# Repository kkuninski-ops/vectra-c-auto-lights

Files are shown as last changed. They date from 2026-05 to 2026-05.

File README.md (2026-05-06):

# Vectra C Auto Lights Controller

Автоматичен контролер за управление на светлините на **Opel Vectra C 2008** с ксенон D1S.
MCU: **ESP32** с вграден Bluetooth (BLE).

## Функции

Всички функции работят **само при AUTO позиция** на копчето за светлини.
При ръчни позиции (0 / габарити / ниски) — factory поведение, контролерът не се намесва.

| Режим | Условие | Светлини |
|---|---|---|
| **Welcome** | Отключване без ключ | конфигурируемо (габарити / мъгла / ксенон) |
| **ACC** | Контакт без двигател | конфигурируемо |
| **DRL** | Двигател работи | ксенон + габарити |
| **Goodbye** | Двигател спира | конфигурируемо |

### DRL — защо така

- Ксенонът светва в момента в който алтернаторът вдига напрежението над 13.2V
- При всяко палене се вижда пълният студен старт на ксенона (синьо/лилаво → бяло) + нивелиране
- Нивелирането е независимо от нашия контролер — задейства се от сигнала на двигателя

### Конфигурация от телефон (BLE)

Свържи се с **"Vectra Auto Lights"** от BLE Terminal приложение и пиши команди:

```
set welcome.lights=GABARI+FOG
set welcome.time=30
set goodbye.lights=GABARI
set goodbye.time=60
set acc.lights=GABARI
set acc.enabled=1
status
reset
```

Вижте [docs/ble-commands.md](docs/ble-commands.md) за пълен списък.

## Хардуер накратко

- **MCU:** ESP32 DevKit v1
- **Ксенон:** IRF4905 P-MOSFET + 2N7000 драйвер (high-side, паралелно на BCM)
- **Габарити / Мъгла:** 12V реле × 2 (паралелно на BCM)
- **Входове:** 3× PC817 оптрон (ACC, AUTO, Unlock) + ADC делител (Vbat)
- **Захранване:** LM7805 от KL30 (постоянно)
- **Защити:** TVS (P6KE15A), реверсна диода, watchdog (ESP32 вграден)

## Структура на репото

```
vectra-c-auto-lights/
├── README.md
├── hardware/
│   └── schematic.md          ← ASCII схема + BOM
├── firmware/
│   ├── platformio.ini        ← PlatformIO конфигурация
│   └── src/
│       ├── main.cpp          ← setup() и loop()
│       ├── common.h          ← споделени константи
│       ├── config.h/cpp      ← конфигурация + NVS съхранение
│       ├── inputs.h/cpp      ← четене на входове + ADC
│       ├── outputs.h/cpp     ← управление на изходи
│       ├── state_machine.h/cpp ← главна логика
│       └── ble_config.h/cpp  ← Bluetooth конфигурация
├── docs/
│   ├── pinout.md             ← точки за свързване в колата
│   └── ble-commands.md       ← BLE команди
└── wiki/                     ← knowledge base
```

## Quick start

1. Инсталирай [PlatformIO](https://platformio.org/)
2. Отвори папка `firmware/` в VS Code
3. Build → Upload към ESP32
4. Свържи се по BLE и провери `status`
5. Свържи хардуера по [hardware/schematic.md](hardware/schematic.md)
6. Намери проводниците в колата по [docs/pinout.md](docs/pinout.md)

## Статус

- [x] Firmware — state machine, BLE, конфигурация
- [x] Хардуерна схема + BOM
- [ ] Намиране на AUTO и Unlock проводници в колата
- [ ] Прототип на breadboard
- [ ] Тест в кола
- [ ] Финален PCB

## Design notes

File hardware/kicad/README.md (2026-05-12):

# KiCad 10 — Vectra C Auto Lights

## Файлове

| Файл | Описание |
|---|---|
| `vectra-auto-lights.kicad_pro` | KiCad проект (design rules, net classes) |
| `vectra-auto-lights.kicad_sch` | Схема (генерирана от `generate_kicad.py`) |
| `vectra-auto-lights.kicad_pcb` | PCB layout (120×80mm, THT компоненти) |
| `generate_kicad.py` | Python скрипт — генерира `.kicad_sch` |

## Генериране на схемата

```bash
cd hardware/kicad
python3 generate_kicad.py
# → vectra-auto-lights.kicad_sch
```

## Отваряне в KiCad 10

1. Отвори `vectra-auto-lights.kicad_pro` с KiCad 10
2. **Schematic Editor** → Tools → Update Symbols from Library
3. Схемата използва **net labels** за всички връзки —
   свежи символите визуално, ако е необходимо
4. **PCB Editor** → отвори `vectra-auto-lights.kicad_pcb`
5. Tools → Update PCB from Schematic (за синхронизиране)

## PCB

- Размер: **120 × 80 mm**
- 2 слоя (F.Cu сигнали, B.Cu GND pour)
- Монтажни отвори: 4× M3 в ъглите
- Всички компоненти THT (during-hole) — лесен ръчен монтаж

## Design Rules

| Параметър | Стойност |
|---|---|
| Min track width | 0.2 mm |
| Power tracks | 0.5 mm |
| Min clearance | 0.2 mm |
| Via diameter | 0.8 mm / drill 0.4 mm |
| Power via | 1.0 mm / drill 0.6 mm |

## Конектори (JST-XH 2.54mm)

| Реф | Пинове | Функция |
|-----|---|---|
| J1 | 3 | KL30, GND, VBAT |
| J2 | 4 | KL18, AUTO, UNLOCK, GND |
| J3 | 5 | BCM_XENON, BCM_GABARI, BCM_FOG, BCM_ILLUM, GND |
| J4 | 5 | XENON_OUT, GABARI_OUT, FOG_OUT, ILLUM_OUT, GND |
| J5 | 2 | +5V → ESP32 VIN, GND |

## Gerber файлове

```bash
# В KiCad PCB Editor:
File → Fabrication Outputs → Gerbers
Output dir: gerbers/
```

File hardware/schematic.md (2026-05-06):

# Хардуерна схема — Vectra C Auto Lights

## Блок схема

```
                        ┌──────────────────────────────────────────────┐
KL30 ──[F1:1A]─────────►│ LM7805 → 5V → ESP32                         │
                        │                                              │
KL30 ──[F2:15A]────────►│ IRF4905 (P-MOSFET) → [D2] ──► Ксенон баласт│
                        │                                              │
KL30 ──[F3:5A]─────────►│ Реле K1 (Габарити)                    ESP32 │◄── BT
                        │ Реле K2 (Мъгла)                             │
                        │                                              │
Vbat ──[47k/10k]───────►│ ADC → детекция на двигател                  │
KL18 ──[PC817]─────────►│ GPIO35 — ACC вход                           │
AUTO ──[PC817]─────────►│ GPIO32 — AUTO вход                          │
UNLOCK─[PC817]─────────►│ GPIO33 — Unlock вход (interrupt)            │
                        └──────────────────────────────────────────────┘
                               │            │           │          │
                           Ксенон       Габарити      Мъгла   Illumination
                          (+BCM via D3) (+BCM via D5) (+BCM via D7) (+BCM via D10)
```

---

## Секция 1 — Захранване на контролера

```
KL30 (+12V постоянно)
  │
 [F1 — предпазител 1A]
  │
 [D1 — 1N4007] ──► (реверсна защита)
  │
 [TVS — P6KE15A] ──► GND  (защита от load dump до ~25V)
  │
 [LM7805]
  IN ──── горе
  GND ─── маса
  OUT ──► [C1: 100µF/25V] + [C2: 100nF] ──► GND
  OUT ──► ESP32 VIN (5V)
```

**Бележка:** LM7805 може да се замени с DC-DC buck (LM2596 модул) за по-малко топлина.

---

## Секция 2 — Детекция на напрежение (двигател работи)

```
KL30 (+12V)
  │
 [R1 — 47kΩ]
  │
  ├──► GPIO34 (ADC)
  │
 [R2 — 10kΩ]
  │
 GND

Vbat = Vadc × 57 / 10
Праг ON : 13.2V (алтернаторът зарежда → двигателят работи)
Праг OFF: 12.8V (хистерезис)
```

---

## Секция 3 — Входове KL18/ACC и AUTO (еднакви схеми)

```
12V сигнал (KL18 или AUTO проводник)
  │
 [R3/R5 — 4.7kΩ]
  │
 PC817 — анод
 PC817 — катод ──► GND

 PC817 — колектор ──► [R4/R6 — 10kΩ] ──► 3.3V
 PC817 — колектор ──► GPIO35 (ACC) / GPIO32 (AUTO)
 PC817 — емитер  ──► GND

Логика: 12V на входа → LED свети → транзистор ON → GPIO = LOW (активен)
```

---

## Секция 4 — Входен Unlock pulse

```
Unlock проводник (12V pulse ~200-500ms при отключване)
  │
 [R7 — 4.7kΩ]
  │
 PC817 — анод
 PC817 — катод ──► GND

 PC817 — колектор ──► [R8 — 10kΩ] ──► 3.3V
 PC817 — колектор ──► GPIO33 (FALLING interrupt)
 PC817 — емитер  ──► GND
```

---

## Секция 5 — Ксенон изход (P-MOSFET high-side)

```
KL30 [F2: 15A] ──► IRF4905 Source
                   IRF4905 Drain ──► [D2 — 1N5408] ──┐
                   IRF4905 Gate ──► [R9 — 10kΩ] ──► KL30 (pull-up → FET OFF по default)
                              └──► [Q2 — 2N7000 Drain]
                                   2N7000 Source ──► GND
                                   2N7000 Gate  ──► [R10 — 1kΩ] ──► GPIO26

BCM xenon изход ──► [D3 — 1N5408] ──┘
                                     │
                               Ксенон баласт (+12V вход)

Логика:
  GPIO26 HIGH → 2N7000 ON → IRF4905 Gate = GND → Vgs = -12V → FET ON → ксенон ON
  GPIO26 LOW  → 2N7000 OFF → R9 pulls Gate = 12V → Vgs = 0V → FET OFF
  D2/D3: развръзка — нито BCM, нито ние не се "виждат" взаимно
```

---

## Секция 6 — Реле за габарити (K1)

```
GPIO27 ──► [R11 — 1kΩ] ──► BC547 база
                            BC547 емитер ──► GND
                            BC547 колектор ──► Реле K1 бобина (-)
                            Реле K1 бобина (+) ──► KL30 [F3]
                            [D8 — 1N4007] антипаралелно на бобината (flyback)

Реле K1 NO  ──► KL30 [F3]
Реле K1 COM ──► [D4 — 1N4007] ──┐
                                  │
BCM габарити изход ──► [D5 — 1N4007] ──┘
                                        │
                                 Габарити (предни + задни)
```

---

## Секция 7 — Реле за мъгла (K2)

```
(Идентично на K1, GPIO14, D6/D7, R12)

GPIO14 ──► [R12 — 1kΩ] ──► BC547 база
                            BC547 емитер ──► GND
                            BC547 колектор ──► Реле K2 бобина (-)
                            Реле K2 бобина (+) ──► KL30 [F3]
                            [D9 — 1N4007] flyback

Реле K2 NO  ──► KL30 [F3]
Реле K2 COM ──► [D6 — 1N4007] ──┐
                                  │
BCM мъгла изход ──► [D7 — 1N4007] ──┘
                                      │
                               Предни мъгли
```

---

## Секция 8 — Illumination изход (табло + радио)

Активира illumination проводника към радиото когато нашата система е включена.
Слаботоков сигнал (~20mA) — без реле, само транзистор + диод.

```
GPIO13 ──► [R13 — 1kΩ] ──► BC547 база
                            BC547 емитер ──► GND
                            BC547 колектор ──► [D10 — 1N4007] ──┐
                                                                  │
BCM illumination изход ──► [D11 — 1N4007] ──────────────────────┘
                                                                  │
                                                    Радио illumination вход
                                                    (+ Табло illumination)

Логика:
  Нашата система активна → GPIO13 HIGH → BC547 ON → 12V към illumination → радиото дима
  MANUAL / OFF → GPIO13 LOW → BC547 OFF → BCM управлява нормално чрез D11
  D10/D11: развръзка — двата источника не се "виждат" взаимно
```

---

## ESP32 Пинове — обобщение

| GPIO | Посока | Функция |
|---|---|---|
| 34 | Вход (ADC) | Напрежение акумулатор (47k/10k делител) |
| 35 | Вход | KL18/ACC оптрон |
| 32 | Вход | AUTO сигнал оптрон |
| 33 | Вход (INT) | Unlock pulse оптрон |
| 26 | Изход | Ксенон MOSFET (2N7000 драйвер) |
| 27 | Изход | Габарити реле (BC547) |
| 14 | Изход | Мъгла реле (BC547) |
| 13 | Изход | Illumination (BC547 + диод) |

---

## BOM (Bill of Materials)

| Реф. | Компонент | Стойност | Бележка |
|---|---|---|---|
| U1 | ESP32 DevKit v1 | — | с вграден BLE |
| U2 | LM7805 | — | TO-220, с радиатор |
| Q1 | IRF4905 | P-MOSFET | TO-220, 74A, -55V |
| Q2 | 2N7000 | N-MOSFET | TO-92, IRF4905 драйвер |
| Q3, Q4, Q5 | BC547 | NPN | TO-92, реле + illumination драйвери |
| OK1 | PC817 | оптрон | KL18/ACC вход |
| OK2 | PC817 | оптрон | AUTO вход |
| OK3 | PC817 | оптрон | Unlock вход |
| K1 | Реле 12V/10A | SPDT | Габарити |
| K2 | Реле 12V/10A | SPDT | Мъгла |
| D1 | 1N4007 | диод | Реверсна защита |
| D2, D3 | 1N5408 | диод 3A | Ксенон развръзка |
| D4–D7 | 1N4007 | диод | Реле развръзка |
| D8, D9 | 1N4007 | диод | Flyback за релета |
| D10, D11 | 1N4007 | диод | Illumination развръзка |
| D12 | P6KE15A | TVS | Защита от load dump |
| R1 | 47kΩ | 1/4W | Vbat делител горе |
| R2 | 10kΩ | 1/4W | Vbat делител долу |
| R3, R5, R7 | 4.7kΩ | 1/4W | PC817 ток ограничители |
| R4, R6, R8 | 10kΩ | 1/4W | Pull-up за PC817 |
| R9 | 10kΩ | 1/4W | IRF4905 gate pull-up |
| R10 | 1kΩ | 1/4W | 2N7000 gate |
| R11, R12, R13 | 1kΩ | 1/4W | BC547 бази |
| C1 | 100µF/25V | електролит | LM7805 изход |
| C2 | 100nF | керамичен | LM7805 декуплинг |
| F1 | 1A | предпазител | MCU захранване |
| F2 | 15A | предпазител | Ксенон верига |
| F3 | 5A | предпазител | Реле захранване |

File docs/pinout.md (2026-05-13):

# Точки за свързване — Opel Vectra C (2002+)

> **Източник:** Ръководство 209, Глава 12 + Схеми на електрическата инсталация  
> ⚠️ Всеки проводник трябва да се провери с мултиметър преди свързване.  
> Цветовете на проводниците може да се различават между отделните варианти на Vectra C.

---

## Бърза справка — всички сигнали

| Сигнал | Местоположение | Проводник / Пин | Бушон | Условие |
|---|---|---|---|---|
| **+12V постоянно** | Блок в багажника, бушон F11 | Add-a-circuit адаптер | F11, 25А | Винаги |
| **Маса (GND)** | Болт за маса под капота | Черен дебел кабел | — | Винаги |
| **+12V при запалено** | ISO конектор зад радиото | Пин A7 — **червен** | F17, 15А | При запалено |
| **Подсветка табло (ILL)** | ISO конектор зад радиото | Пин A1 — **оранжев** | F17, 15А | При светлини |
| **AUTO сигнал** | Конектор на лоста за светлини (ляво от волана) | Сканирай при AUTO позиция | — | При AUTO |
| **Отключване (pulse)** | Конектор на мотора на брава — водителска врата | Проводник с +12В за ~0.3 сек | — | При отключване |
| **Габаритни светлини** | Конектор на предна фара (от моторния отсек) | Проводник с 12В само при габарити | F8, 10А | При габарити |
| **Мъгловки** | Конектор на мъгловката в предния бампер | Проводник с 12В при мъгла | F8, 10А | При мъгла |
| **Ксенон баласт** | Конектор на баласта на фарата | Жълт — 12В при къси светлини | F8, 10А | При къси светлини |

---

## Блокове с предпазители — местоположение

Колата има **три блока** с предпазители и релета:

| Блок | Местоположение | Достъп |
|---|---|---|
| **Табло (вътрешен)** | Вляво под волана, в купето | Свали капачката |
| **Под капака** | Моторен отсек, до акумулатора | Отвори капака |
| **Багажник** | В багажника, лява странична обшивка | Свали обшивката |

---

## 1. Постоянно +12V (Клема 30)

**Описание:** Захранване директно от акумулатора — има напрежение дори при изключено запалване.

| Вариант | Местоположение | Бушон |
|---|---|---|
| Акумулатор (+) | Директно, с добавен бушон 15А | Монтирай свой |
| Блок в багажника №11 | Клема 30, 25А | F11 |
| Блок в багажника №24 | Клема 30, 25А | F24 |
| Блок под капака №24 | Клема 30, 30А | F24 |

**Препоръка:** Използвай **Add-a-circuit адаптер** в блока на багажника, бушон F11 — най-лесен достъп.

---

## 2. Маса (GND)

**Описание:** Отрицателен полюс — свързан към купето на колата.

- **Под капака** — болт за маса вляво при окачването (дебел черен кабел от акумулатора)
- **В купето** — болт за маса под арматурното табло, при педалите
- **Акумулатор (-)** — директно при необходимост

---

## 3. Захранване при запалено (Клема 15 / ACC)

**Описание:** 12V само при включено запалване.

| Вариант | Местоположение | Бушон |
|---|---|---|
| Блок на таблото №17 | Комбинация от уреди, 15А | F17 |
| ISO конектор зад радиото | Пин A7 — червен проводник | — |

**Препоръка:** Вземи от **ISO конектора зад радиото**:
- Пин **A7 (червен)** = 12V при запалено
- Пин **A4 (жълт)** = 12V постоянно (Клема 30)

---

## 4. Подсветка на таблото (ILL)

**Описание:** Активира се при включени габарити или светлини — използва се за подсветка на радиото и бутоните.

| Вариант | Местоположение |
|---|---|
| ISO конектор зад радиото | Пин A1 — **оранжев** проводник |
| Конектор на превключвателя за светлини | При лоста (ляво от волана) |
| Конектор на арматурното табло | Оранжев проводник към потенциометъра за яркост |

**Препоръка:** ISO конекторът зад радиото е най-удобен — пин A1, оранжев.

---

## 5. Сигнал AUTO

**Описание:** Сигналът от AUTO позицията на превключвателя за светлини.

На Vectra C превключвателят за светлини (лост вляво от волана, компонент S121) има позиция AUTO при версиите с автоматично осветление. Ако твоята кола **няма** AUTO позиция — монтирай отделен превключвател.

**Как да намериш пина:**
1. Извади конектора на лоста за светлини
2. Завърти лоста на AUTO позиция
3. С мултиметър провери всеки пин спрямо маса
4. Пинът, на който се появява 12V **само** при AUTO = сигналът

---

## 6. Сигнал ОТКЛЮЧВАНЕ (централно заключване)

**Описание:** Кратък импулс при натискане на "отключване" на дистанционното. Идва от централния управляващ модул (BCM) към мотора на брава.

### Компоненти на централното заключване:

| Компонент | Означение | Местоположение |
|---|---|---|
| Главен управляващ модул (BCM) | A15 | Под арматурното табло |
| Модул на водителска врата | A28D | Вътре в водителска врата |
| Модул на пасажерска врата | A28P | Вътре в пасажерска врата |
| Реле централно заключване | K8 | Блок в багажника |
| Мотор на брава — водителска врата | Y13D | Водителска врата |
| Мотор на брава — пасажерска врата | Y13P | Пасажерска врата |
| Мотори на задни врати | Y35L / Y35R | Задни врати |
| Мотор на багажника | Y10 | Задна врата |

### Как да намериш сигнала:

**При мотора на брава на водителска врата (Y13D) — препоръчително:**
1. Открий конектора на мотора на брава (под обшивката на вратата)
2. Провери двата проводника с мултиметър при отключване с дистанционното
3. При **отключване**: единият проводник получава +12В за ~0.3–0.5 сек
4. При **заключване**: другият проводник получава +12В

---

## 7. Габаритни светлини

**Описание:** Лампи W 5W в предните фарове — включват се при позиция "габарити" или "светлини".

**Тип лампа:** W 5W (щифтова)  
**Местоположение:** На рефлектора на фарата, до лампата за дълги светлини  
**Достъп:** От моторния отсек, завъртане на патрона

**Как да намериш проводника:**
- Открий конектора на предната фара (от моторния отсек)
- Провери проводниците при включване **само на габарити** (без ниски светлини)
- Проводникът, на който се появява 12В = сигналът

**Бушон:** Блок под капака, №8 — Фарове, 10А

---

## 8. Мъгловки (противотуманни фарове)

**Описание:** H3 55W лампи в предния бампер.

**Тип лампа:** H3, 55W  
**Местоположение:** В предния бампер, долна позиция  
**Достъп:** Отдолу или след сваляне на обшивката на бампера

**Как да намериш проводника:**
- Открий конектора на мъгловката (вдясно или вляво в бампера)
- Провери при включване **само на мъгловките**
- Проводникът с 12В = сигналът

---

## 9. Ксенонов баласт

**Описание:** Ксенонови фарове D2S — баластът получава 12V при включени къси светлини.

**Тип лампа:** D2S  
**Местоположение:** Баластът е монтиран директно на фарата  
**Бушон:** Блок под капака, №8 — Фарове, 10А

| Проводник | Описание | Типичен цвят |
|---|---|---|
| Захранване | +12V при включени къси светлини | Жълт |
| Маса | GND | Кафяв / черен |

> ⚠️ **Внимание:** Не докосвай проводниците **към самата лампа** — около 25 000V при стартиране!  
> Свързвай се само към проводниците от управляващия модул **към баласта**.

---

## Ред при монтаж

1. **Изключи акумулатора** преди работа
2. **KL30** — Add-a-circuit в блока на багажника, бушон F11
3. **Маса** — болт под капота
4. **KL15 и ILL** — ISO конектор зад радиото (пин A7 и A1)
5. **ОТКЛЮЧВАНЕ** — конектор на мотора на брава на водителска врата
6. **Габарити** — конектор на предна фара
7. **Мъгловки** — конектор на мъгловката в бампера
8. **Ксенон** — конектор на баласта
9. **AUTO** — конектор на лоста за светлини

---

## Инструменти

| Инструмент | Употреба |
|---|---|
| Мултиметър (20V DC) | Намиране на сигнали |
| Игловидна сонда | Пробиване на изолацията без рязане |
| Posi-Tap конектори | Захващане без рязане на проводника |
| Add-a-circuit адаптер | За бушоните |
| 12V тест лампа | Бързо проверяване на импулси |

---

> 📖 **Схеми в ръководството:** Схема 9–11 (централно заключване, стр. 328–330) · Схема 13 (осветление и табло, стр. 332) · Схема 16 (фарове и мъгловки, стр. 335)

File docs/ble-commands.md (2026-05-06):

# Bluetooth конфигурация

## Свързване

1. Инсталирай **"Serial Bluetooth Terminal"** (Android) или **"BLE Terminal HM-10"** (iOS)
2. Включи контакта на колата (ESP32 се захранва от KL30 — включен е винаги)
3. В приложението: търси устройство **"Vectra Auto Lights"**
4. Свържи се → избери **Nordic UART Service**
5. Пиши команди в конзолата

---

## Команди

### `status`
Показва текущото състояние и всички настройки.

```
Състояние: DRL
Акумулатор: 14.12V

welcome.lights  = GABARI+FOG
welcome.time    = 30s
goodbye.lights  = GABARI
goodbye.time    = 45s
acc.lights      = GABARI
acc.enabled     = yes
```

### `set KEY=VALUE`
Сменя настройка. Записва се автоматично в паметта.

**Примери:**
```
set welcome.lights=GABARI+FOG+XENON
set welcome.time=20
set goodbye.lights=GABARI
set goodbye.time=60
set acc.lights=GABARI
set acc.enabled=0
set acc.enabled=1
```

**Стойности за светлини:**
- `GABARI` — само габарити (предни + задни)
- `FOG` — само предни мъгли
- `XENON` — само ксенон (⚠️ студен старт!)
- `GABARI+FOG` — комбинация
- `GABARI+FOG+XENON` — всичко
- `NONE` — нищо (изключен режим)

### `reset`
Връща всички настройки към стойностите по подразбиране.

### `help`
Показва кратка помощ.

---

## Настройки по подразбиране

| Настройка | Default |
|---|---|
| welcome.lights | GABARI |
| welcome.time | 30s |
| goodbye.lights | GABARI |
| goodbye.time | 30s |
| acc.lights | GABARI |
| acc.enabled | yes |

---

## Бележка за ксенон в welcome/goodbye

D1S ксенонът има ограничен брой студени старта. Ако е включен в welcome lights, след края на таймера ще се изгаси, и след малко ще се запали отново при стартиране на двигателя — **два студени старта наведнъж**.

Изключение: ако двигателят запали по време на welcome таймера, ксенонът **не се изгася** — директно преминава в DRL режим.

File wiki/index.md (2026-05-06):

# Wiki Index — Vectra C Auto Lights

## Entities

*(добавяй при ingest на нови sources)*

| Файл | Описание |
|---|---|
| — | — |

## Concepts

| Файл | Описание |
|---|---|
| — | — |

## Sources

| Файл | Тип | Описание |
|---|-----|---|
| — | — | — |

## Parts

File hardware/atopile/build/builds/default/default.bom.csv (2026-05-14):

Designator | Footprint | Quantity | Value | Manufacturer | Partnumber | LCSC Part #
C1 | Nichicon_UBT1E101MPD1TD:CAP-TH_BD8.0-P3.50-D0.5-FD | 1 |  | Nichicon | UBT1E101MPD1TD | C1579560
C2 | KEMET_C315C104M5U5TA:C_Disc_D5.0mm_W2.5mm_P2.50mm | 1 |  | KEMET | C315C104M5U5TA | C1711
D1, D2, D3, D4, D5, D6, D7, D8, D9 | ST_1N4007:DO-41_BD2.4-L4.7-P8.70-D0.9-RD | 9 |  | ST | 1N4007 | C106903
D10 | RUILON_P6KE15A:DO-15_BD3.1-L6.7-P10.70-D0.9-FD | 1 |  | RUILON | P6KE15A | C10182
D11, D12 | MDD_Microdiode_Electronics_1N5408:DO-201_BD5.3-L9.5-P13.50-D1.4-RD | 2 |  | MDD（Microdiode Electronics） | 1N5408 | C2460
F1, F2, F3 | Schurter_FuseHolder_5x20:Fuseholder_Cylinder-5x20mm_Schurter_0031_8201_Horizontal_Open | 3 |  | Schurter | 0031.8201 | C2837835
J1 | BOOMELE_PinHeader_1x2_P254:PinHeader_1x02_P2.54mm_Vertical | 1 |  | BOOMELE | 2.54-1*2P | C49256
J2 | BOOMELE_PinHeader_1x4_P254:PinHeader_1x04_P2.54mm_Vertical | 1 |  | BOOMELE | 2.54-1*4P | C49661
J3, J4, J5, J6 | BOOMELE_2_54_1_3P:HDR-TH_3P-P2.54-V-M-1 | 4 |  | BOOMELE | 2.54-1*3P针 | C49257
K1, K2 | Ningbo_Songle_Relay_SRD_12VDC_SL_C:RELAY-TH_SRD-XXVDC-XL-C | 2 |  | Ningbo Songle Relay | SRD-12VDC-SL-C | C30431
Q1, Q2, Q3 | Jiangsu_Changjing_Electronics_Technology_Co___Ltd_BC547:TO-92-3_L4.9-W3.7-P1.27-L | 3 |  | Jiangsu Changjing Electronics Technology Co., Ltd. | BC547 | C47089404
Q4 | Vishay_IRF4905PBF:TO-220-3_Vertical | 1 |  | Vishay | IRF4905PBF | C2564
Q5 | Changjiang_Electronics_Tech_2N7000:TO-92-3_L4.9-W3.7-P1.27-L | 1 |  | Changjiang Electronics Tech | 2N7000 | C9114
R1, R2, R3, R13 | UNI_ROYAL_MFR0W4F1000A50:RES-TH_BD2.2-L6.5-P10.50-D0.6 | 4 |  | UNI-ROYAL | MFR0W4F1000A50 | C57438
R4, R6, R8 | UNI_ROYAL_MFR0W4F4701A50:RES-TH_BD2.2-L6.5-P10.50-D0.6 | 3 |  | UNI-ROYAL | MFR0W4F4701A50 | C57204
R5, R7, R9, R11, R12 | UNI_ROYAL_MFR0W4F1002A50:RES-TH_BD2.5-L6.5-P10.50-D0.6 | 5 |  | UNI-ROYAL | MFR0W4F1002A50 | C57436
R10 | UNI_ROYAL_MFR0W4F4702A50:RES-TH_BD2.5-L6.5-P10.50-D0.6 | 1 |  | UNI-ROYAL | MFR0W4F4702A50 | C58605
U1, U2, U3 | UMW_PC817C:DIP-4_L4.6-W6.5-P2.54-LS7.6-BL | 3 |  | UMW | PC817C | C3008368
U4 | HGSEMI_LM7805CT:TO-220-3_L10.0-W4.5-P2.54-L | 1 |  | HGSEMI | LM7805CT | C725349
U5 | Espressif_Systems_ESP32_WROOM_32E_N4:WIFI-SMD_ESP32-WROOM-32E | 1 |  | Espressif Systems | ESP32-WROOM-32E-N4 | C701341

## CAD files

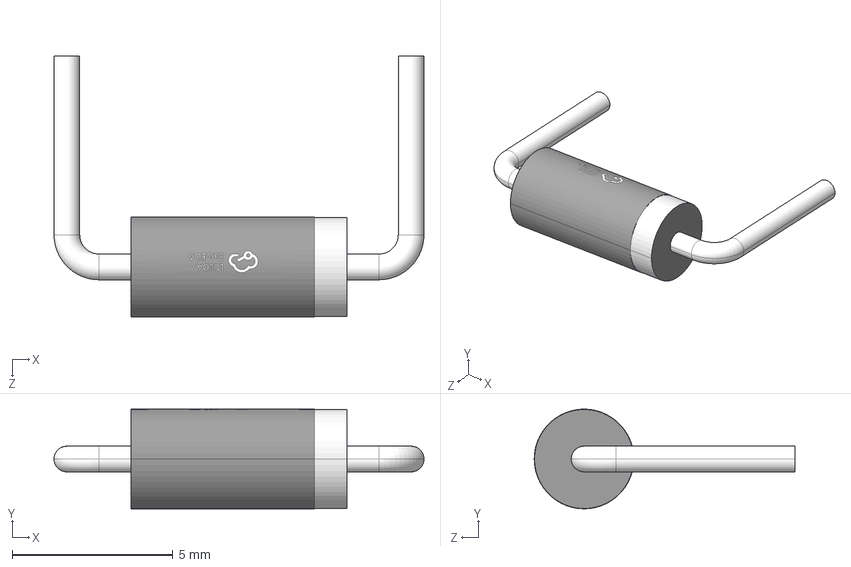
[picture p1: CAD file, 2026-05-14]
hardware/atopile/build/cache/parts/easyeda/C10182/DO-15_BD3.1-L6.7-P10.70-D0.9-FD.step
11.5 x 3.10 x 8.10 mm

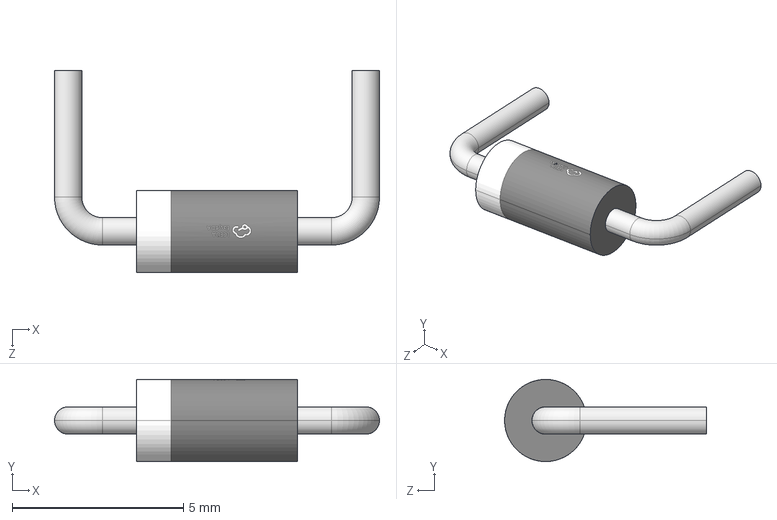
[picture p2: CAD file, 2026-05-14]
hardware/atopile/build/cache/parts/easyeda/C106903/DO-41_D2.4-L4.7-P8.70.step
9.50 x 2.40 x 5.90 mm

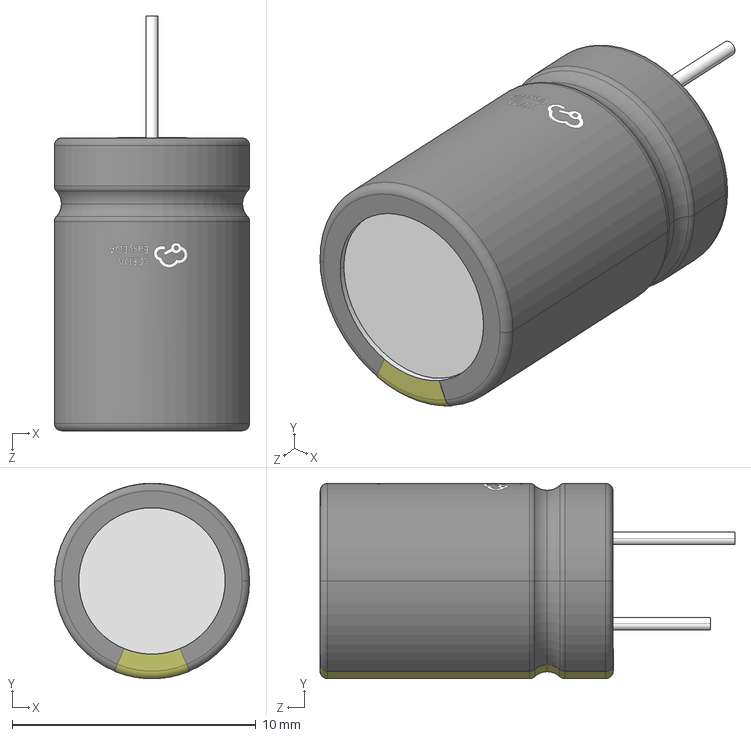
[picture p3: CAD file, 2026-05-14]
hardware/atopile/build/cache/parts/easyeda/C1579560/CAP-TH_BD8.0-P3.50-D0.5-FD.step
8.00 x 8.00 x 17.0 mm

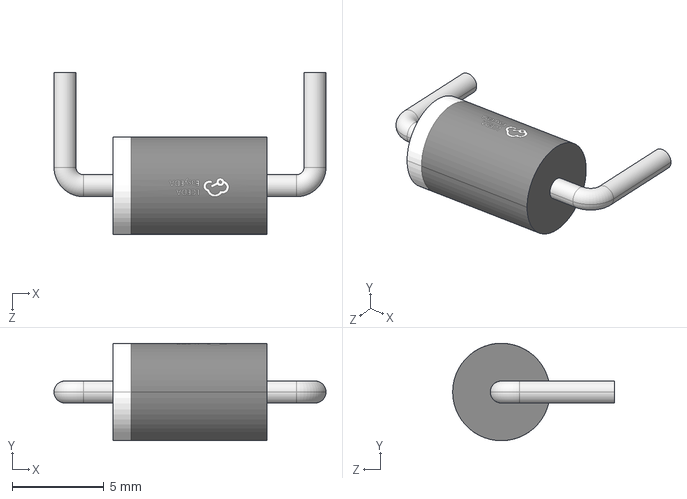
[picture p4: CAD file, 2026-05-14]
hardware/atopile/build/cache/parts/easyeda/C2460/DO-201AD_D5.3-L8.4-P13.6.step
14.8 x 5.30 x 8.80 mm

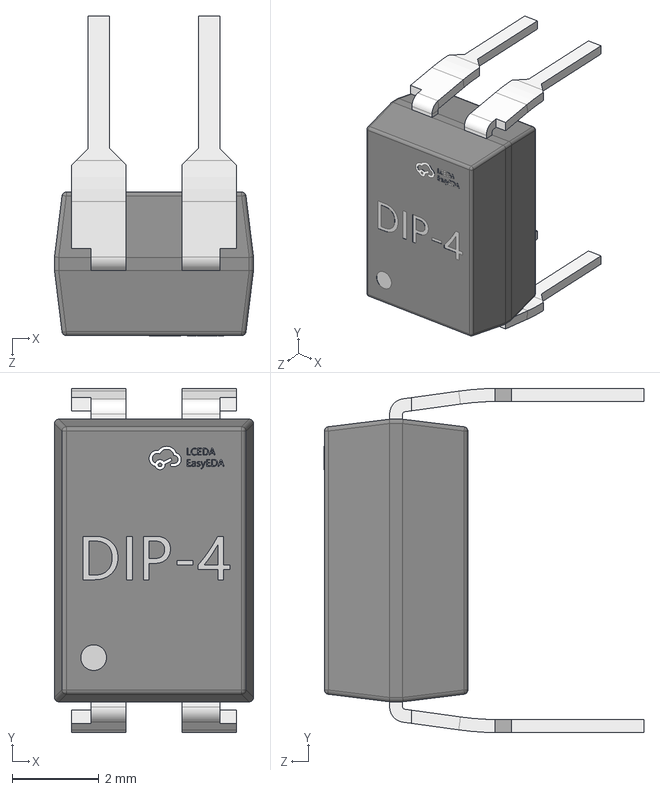
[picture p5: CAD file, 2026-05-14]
hardware/atopile/build/cache/parts/easyeda/C3008368/DIP-4_L4.6-W6.5-H3.5-LS7.62-P2.54.step
4.58 x 7.92 x 7.36 mm

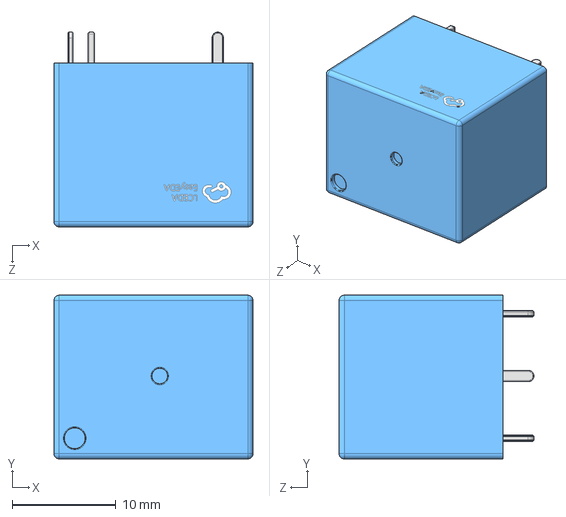
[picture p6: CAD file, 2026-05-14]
hardware/atopile/build/cache/parts/easyeda/C30431/RELAY-TH_L19.2-W15.6-H15.8.step
19.2 x 15.8 x 18.8 mm

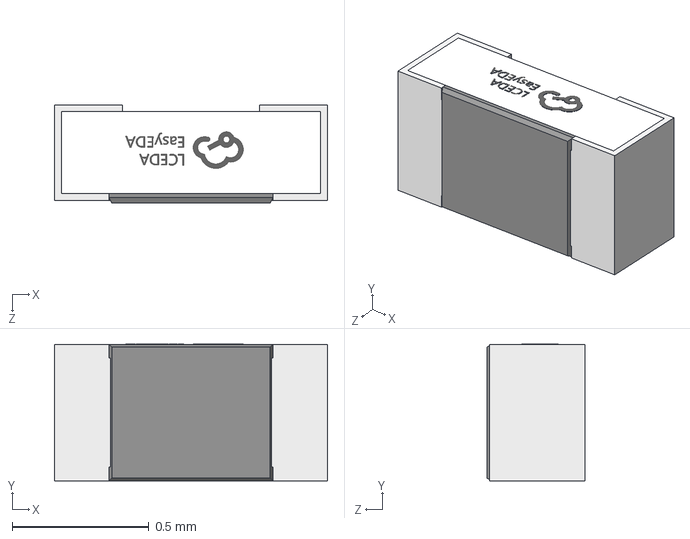
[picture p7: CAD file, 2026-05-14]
hardware/atopile/build/cache/parts/easyeda/C36871/R0402_L1.0-W0.5-H0.4.step
1.00 x 0.501 x 0.36 mm

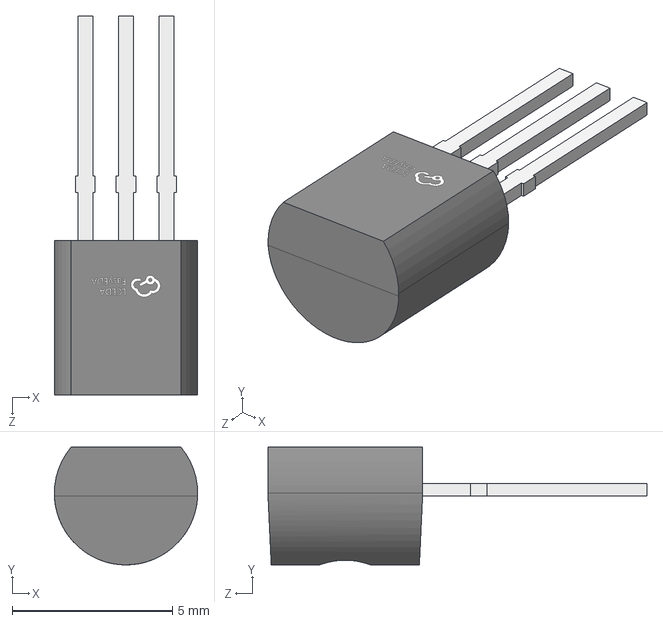
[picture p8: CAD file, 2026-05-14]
hardware/atopile/build/cache/parts/easyeda/C47089404/TO-92-3_L4.9-W3.7-P1.27-L.step
4.48 x 3.68 x 11.8 mm

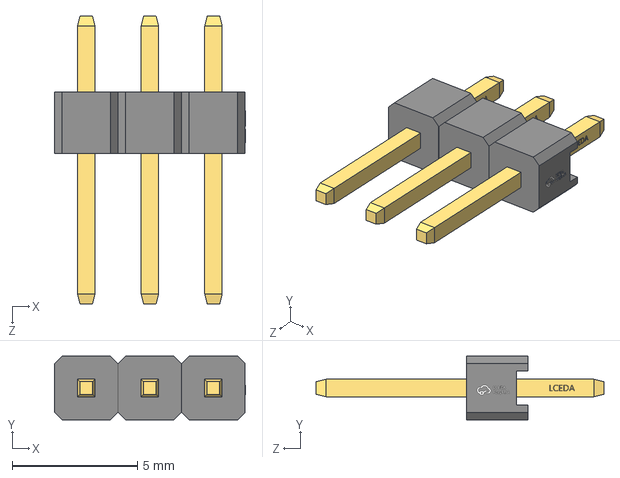
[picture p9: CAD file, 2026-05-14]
hardware/atopile/build/cache/parts/easyeda/C49257/HDR-M-2.54_1x3.step
7.63 x 2.54 x 11.5 mm

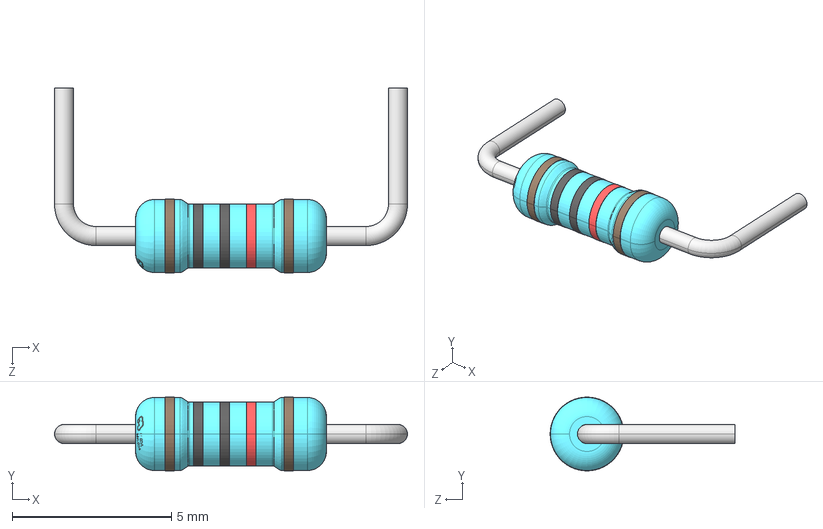
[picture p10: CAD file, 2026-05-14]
hardware/atopile/build/cache/parts/easyeda/C57204/RES-TH_BD2.2-L6.5-P10.50-D0.6.step
11.1 x 2.32 x 5.81 mm

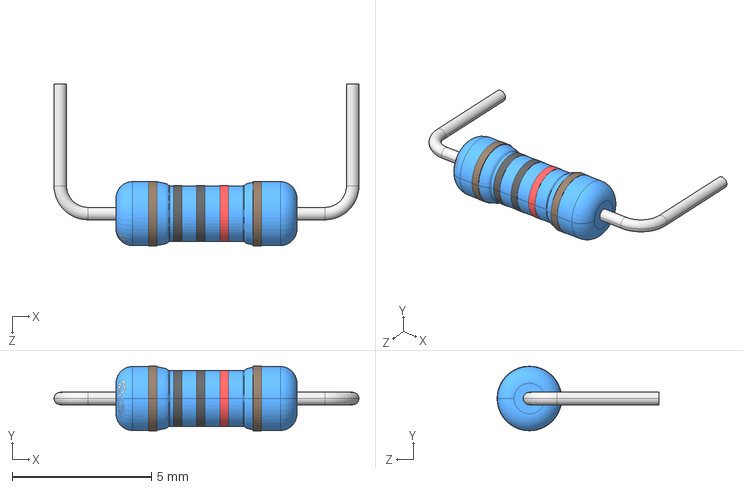
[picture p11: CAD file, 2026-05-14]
hardware/atopile/build/cache/parts/easyeda/C57436/RES-TH_D2.3-L6.5-P10.50.step
11.0 x 2.32 x 5.81 mm

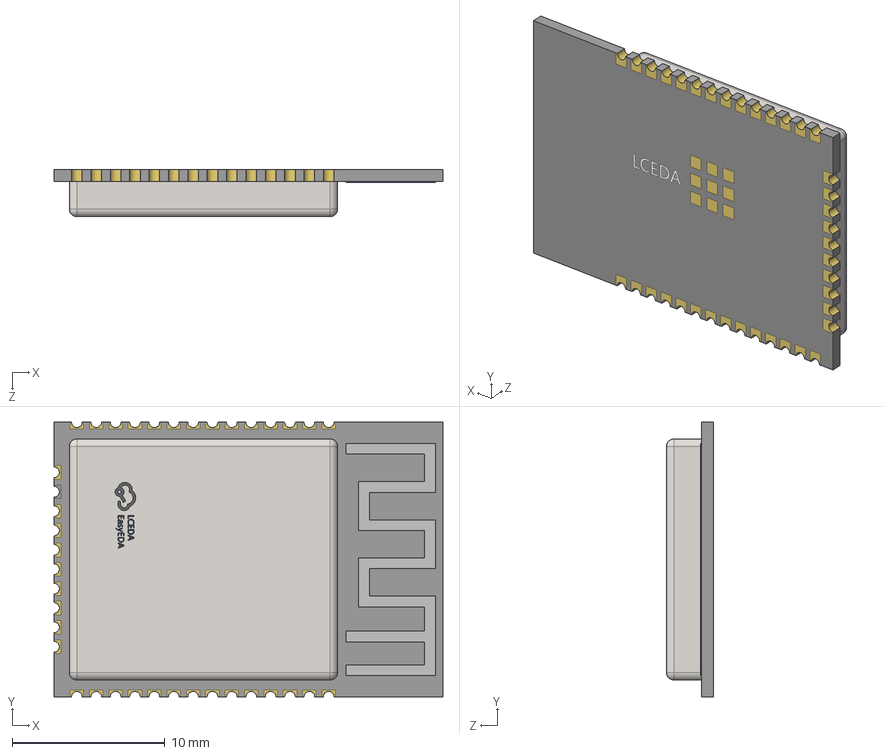
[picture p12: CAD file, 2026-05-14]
hardware/atopile/build/cache/parts/easyeda/C701341/WIFI-SMD_L25.5-W18.0-H3.1-ESP32-WROOM-32E.step
25.5 x 18.0 x 3.10 mm

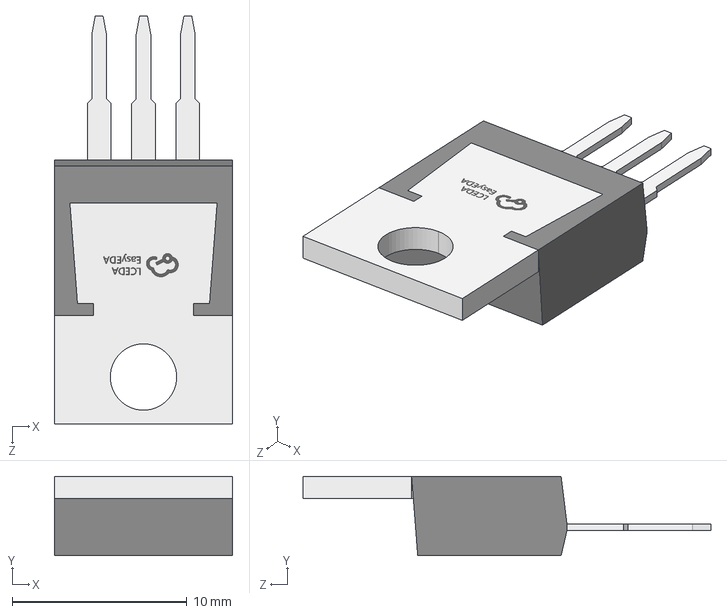
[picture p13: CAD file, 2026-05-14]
hardware/atopile/build/cache/parts/easyeda/C725349/TO-220-3_L10.0-W4.5-P2.54-L.step
10.2 x 4.54 x 23.4 mm

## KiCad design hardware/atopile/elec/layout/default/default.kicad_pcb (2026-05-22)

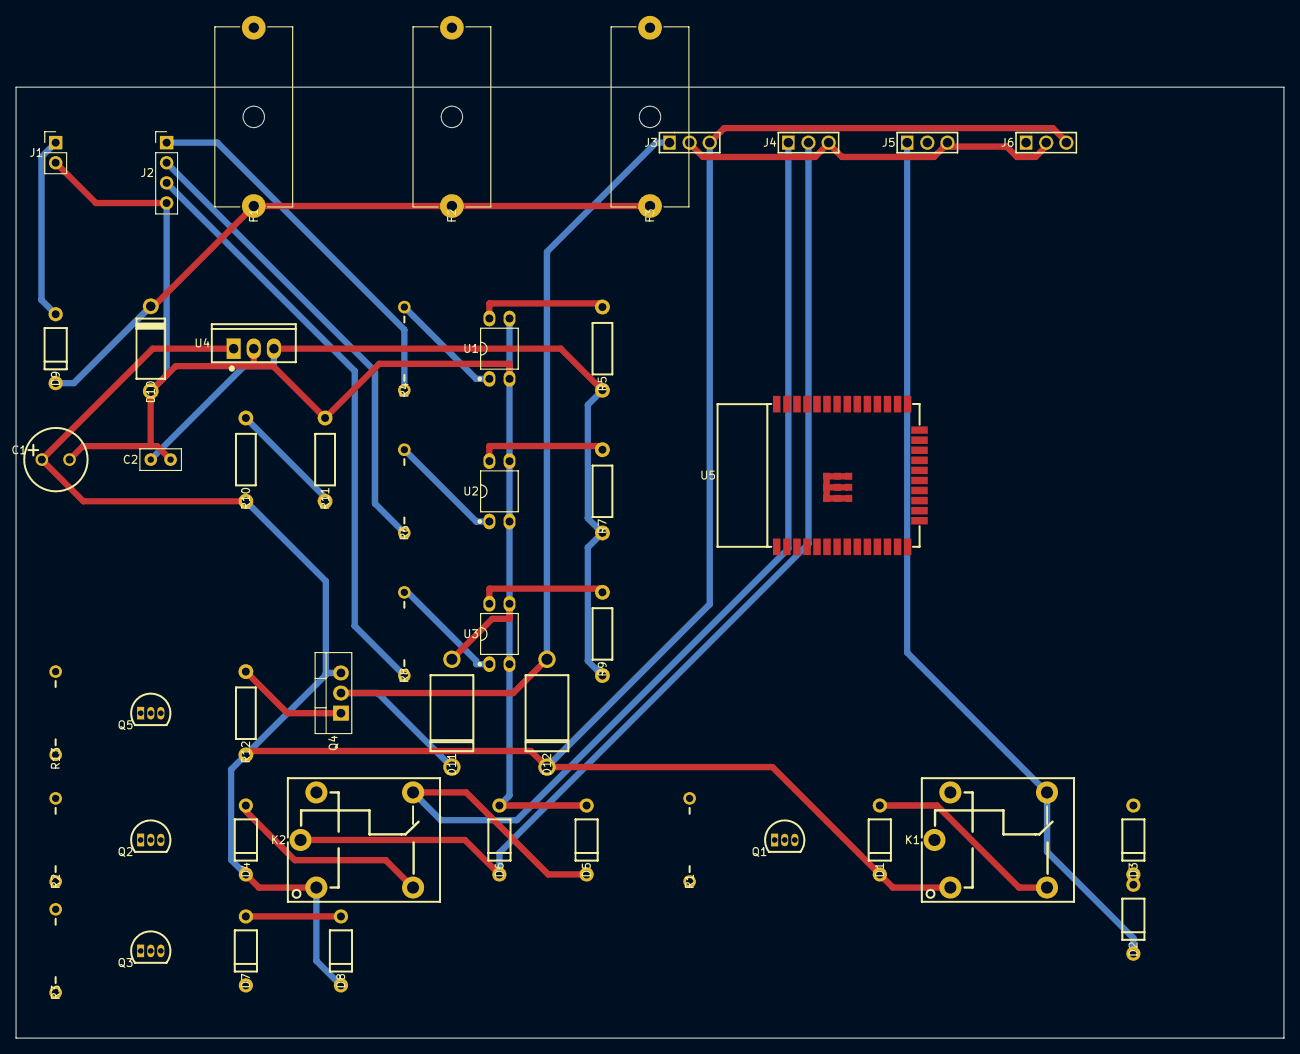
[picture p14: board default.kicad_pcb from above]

Board: 2 copper layers, 160.0 x 120.0 mm, 48 parts (0 on the bottom side), 32 nets.

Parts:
C1: CAP-TH_BD8.0-P3.50-D0.5-FD
C2: C_Disc_D5.0mm_W2.5mm_P2.50mm
D1, D2, D3, D4, D5, D6, D7, D8, D9: DO-41_BD2.4-L4.7-P8.70-D0.9-RD
D10: DO-15_BD3.1-L6.7-P10.70-D0.9-FD
D11, D12: DO-201_BD5.3-L9.5-P13.50-D1.4-RD
F1, F2, F3: Fuseholder_Cylinder-5x20mm_Schurter_0031_8201_Horizontal_Op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
J1: PinHeader_1x02_P2.54mm_Vertical
J2: PinHeader_1x04_P2.54mm_Vertical
J3, J4, J5, J6: HDR-TH_3P-P2.54-V-M-1
K1, K2: RELAY-TH_SRD-XXVDC-XL-C
Q1, Q2, Q3, Q5: TO-92-3_L4.9-W3.7-P1.27-L
Q4: TO-220-3_Vertical
R1, R2, R3, R4, R6, R8, R13: RES-TH_BD2.2-L6.5-P10.50-D0.6
R5, R7, R9, R10, R11, R12: RES-TH_BD2.5-L6.5-P10.50-D0.6
U1, U2, U3: DIP-4_L4.6-W6.5-P2.54-LS7.6-BL
U4: TO-220-3_L10.0-W4.5-P2.54-L
U5: WIFI-SMD_ESP32-WROOM-32E

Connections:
1: D9.1, D10.2, F1.1, F2.1, F3.1
2: D1.2, K1.2, Q1.1
AN: R4.2, U1.1
D: Q4.1, Q5.3, R12.2
com: D2.1, J5.1, K1.3
com-1: D5.1, J4.1, K2.3
ctrl: R1.1, U5.33
ctrl-1: R2.1, U5.31
ctrl-2: R3.1, U5.36
ctrl-3: R13.1, U5.30
fog-2: Q1.2, R1.2
gabari-2: D4.2, K2.2, Q2.1
gabari-2-1: Q2.2, R2.2
gnd: C1.2, C2.2, D2.2, D3.2, D5.2, D6.2, D7.2, D8.2, D10.1, D11.2, J1.2, J2.4, J3.2, J4.3, J5.3, J6.2, Q1.3, Q2.3, Q3.3, Q5.1, R11.2, U1.2, U1.3, U2.2, U2.3, U3.2, U3.3, U4.2, U5.1, U5.15, U5.38, U5.39
illum-2: Q3.2, R3.2
no: D3.1, J5.2, K1.5
no-1: D6.1, J4.2, K2.5
ok2-AN: R6.2, U2.1
ok3-AN: R8.2, U3.1
out_illum: D7.1, J6.1, Q3.1
out_xenon: D11.1, D12.2, J3.1, Q4.2
sig_auto: J2.2, R6.1
sig_in: J2.1, R4.1
sig_out: R5.2, U1.4, U5.27
sig_out-1: R7.2, U2.4, U5.28
sig_out-2: R9.2, U3.4, U5.29
sig_unlock: J2.3, R8.1
v12: C1.1, D1.1, D4.1, D8.1, D12.1, F1.2, F2.2, F3.2, J3.3, J6.3, K1.1, K2.1, Q4.3, R10.1, R12.1, U4.1
v33: C2.1, R5.1, R7.1, R9.1, U4.3, U5.2
vin_raw: D9.2, J1.1
vout: R10.2, R11.1, U5.26
xenon-2: Q5.2, R13.2

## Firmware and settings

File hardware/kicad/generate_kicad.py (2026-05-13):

#!/usr/bin/env python3
"""
Vectra C Auto Lights — KiCad 10 Schematic Generator
Generates: vectra-auto-lights.kicad_sch

Usage:
    cd hardware/kicad
    python3 generate_kicad.py
    # → отвори vectra-auto-lights.kicad_sch в KiCad 10

Схемата използва net labels за всички връзки.
След отваряне в KiCad: свържи всеки пин с nearby label (5-10 мин работа).
"""

import uuid
import os

OUT = os.path.join(os.path.dirname(__file__), "vectra-auto-lights.kicad_sch")

# ── Helpers ───────────────────────────────────────────────────────────

def uid():
    return str(uuid.uuid4())

def prop(name, val, x=0, y=0, rot=0, hide=False):
    h = " hide" if hide else ""
    return (f'    (property "{name}" "{val}" (at {x:.4f} {y:.4f} {rot})\n'
            f'      (effects (font (size 1.27 1.27)){h})\n'
            f'    )')

def label(net, x, y, rot=0):
    return (f'  (label "{net}" (at {x:.4f} {y:.4f} {rot})\n'
            f'    (effects (font (size 1.27 1.27)) (justify left))\n'
            f'    (uuid "{uid()}")\n'
            f'  )')

def wire(x1, y1, x2, y2):
    return (f'  (wire (pts (xy {x1:.4f} {y1:.4f}) (xy {x2:.4f} {y2:.4f}))\n'
            f'    (stroke (width 0) (type default))\n'
            f'    (uuid "{uid()}")\n'
            f'  )')

def no_connect(x, y):
    return f'  (no_connect (at {x:.4f} {y:.4f}) (uuid "{uid()}"))'

def power_symbol(name, x, y):
    """Power rail symbol (+12V, +5V, GND)"""
    return (f'  (symbol (lib_id "power:{name}") (at {x:.4f} {y:.4f} 0) (unit 1)\n'
            f'    (exclude_from_sim no) (in_bom yes) (on_board yes)\n'
            f'    (uuid "{uid()}")\n'
            f'{prop("Reference", f"#{name}", x, y-2.54, 0, True)}\n'
            f'{prop("Value", name, x, y+2.54, 0)}\n'
            f'    (pin "1" (uuid "{uid()}"))\n'
            f'  )')

# ── Component factory ─────────────────────────────────────────────────

class Comp:
    """Builds a KiCad symbol instance."""
    def __init__(self, lib_id, ref, value, x, y, rot=0, footprint="", datasheet="~"):
        self.lib_id    = lib_id
        self.ref       = ref
        self.value     = value
        self.x         = x
        self.y         = y
        self.rot       = rot
        self.footprint = footprint
        self.datasheet = datasheet
        self.pins      = {}   # name → (dx, dy)  offsets relative to component center
        self.labels    = []   # (net, dx, dy) for auto-labels

    def pin_label(self, net, dx, dy):
        """Add a net label near a pin."""
        self.labels.append((net, dx, dy))
        return self

    def render(self):
        lines = [
            f'  (symbol (lib_id "{self.lib_id}") (at {self.x:.4f} {self.y:.4f} {self.rot}) (unit 1)',
            f'    (exclude_from_sim no) (in_bom yes) (on_board yes)',
            f'    (uuid "{uid()}")',
            prop("Reference", self.ref,    self.x+1,   self.y-2.54, 0),
            prop("Value",     self.value,  self.x+1,   self.y+2.54, 0),
            prop("Footprint", self.footprint, self.x, self.y, 0, True),
            prop("Datasheet", self.datasheet, self.x, self.y, 0, True),
        ]
        # Generic pin UUIDs (1..8)
        for i in range(1, 9):
            lines.append(f'    (pin "{i}" (uuid "{uid()}"))')
        lines.append('  )')
        # Net labels near pins
        for (net, dx, dy) in self.labels:
            lines.append(label(net, self.x + dx, self.y + dy))
        return "\n".join(lines)


# ── Net definitions ───────────────────────────────────────────────────
# Naming convention:
#   PWR_12V, PWR_5V, GND      — power rails
#   KL18_RAW, AUTO_RAW        — 12V raw car signals (before optocouplers)
#   UNLOCK_RAW                — 12V unlock pulse
#   ACC_GPIO, AUTO_GPIO       — 3.3V signals to ESP32 (after optocouplers)
#   UNLOCK_GPIO               — 3.3V unlock to ESP32
#   VBAT_ADC                  — voltage divider output to ESP32 ADC
#   GPIO13..GPIO35            — ESP32 GPIO outputs/inputs
#   XENON_GATE                — 2N7000 drain / IRF4905 gate
#   XENON_SW                  — IRF4905 drain (our xenon output, before diode)
#   BCM_XENON                 — BCM xenon output (before diode)
#   XENON_BALLAST             — final +12V to xenon ballast
#   GABARI_SW                 — relay K1 NO contact
#   BCM_GABARI                — BCM gabari output
#   GABARI_WIRE               — final gabari output to car
#   FOG_SW                    — relay K2 NO contact
#   BCM_FOG                   — BCM fog output
#   FOG_WIRE                  — final fog output to car
#   ILLUM_SW                  — our illumination transistor output
#   BCM_ILLUM                 — BCM illumination output
#   ILLUM_WIRE                — final illumination to radio
#   XENON_PWR                 — +12V fused 15A (xenon power)
#   RELAY_PWR                 — +12V fused 5A (relay power)
#   RELAY_K1_COIL_N           — K1 coil negative (collector Q3)
#   RELAY_K2_COIL_N           — K2 coil negative (collector Q4)


# ── Build component list ──────────────────────────────────────────────

components = []

# ═══════════════════════════════════════════════════════════════════════
# БЛОК A — ЗАХРАНВАНЕ  (x: 15-110, y: 15-55)
# ═══════════════════════════════════════════════════════════════════════

# J1 — КL30 + GND вход (2-pin)
j1 = Comp("Connector:Conn_01x02_Pin", "J1", "KL30+GND", 18, 28,
           footprint="Connector_PinHeader_2.54mm:PinHeader_1x02_P2.54mm_Vertical")
j1.pin_label("PWR_12V",  5,  -2.54)
j1.pin_label("GND",      5,   2.54)
components.append(j1)

# F1 — предпазител 1A (MCU)
f1 = Comp("Device:Fuse", "F1", "1A", 38, 20,
          footprint="Fuse:Fuseholder_Littelfuse_64900001039_1x1_P5.08mm_Vertical")
f1.pin_label("PWR_12V",  -5,  0)
f1.pin_label("PWR_12V_1A", 5,  0)
components.append(f1)

# F2 — предпазител 15A (ксенон)
f2 = Comp("Device:Fuse", "F2", "15A", 38, 30,
          footprint="Fuse:Fuseholder_Littelfuse_64900001039_1x1_P5.08mm_Vertical")
f2.pin_label("PWR_12V",    -5, 0)
f2.pin_label("XENON_PWR",   5, 0)
components.append(f2)

# F3 — предпазител 5A (релета)
f3 = Comp("Device:Fuse", "F3", "5A", 38, 40,
          footprint="Fuse:Fuseholder_Littelfuse_64900001039_1x1_P5.08mm_Vertical")
f3.pin_label("PWR_12V",  -5, 0)
f3.pin_label("RELAY_PWR", 5, 0)
components.append(f3)

# D1 — 1N4007 реверсна защита
d1 = Comp("Device:D", "D1", "1N4007", 62, 20,
          footprint="Diode_THT:D_DO-41_SOD81_P10.16mm_Horizontal")
d1.pin_label("PWR_12V_1A", -5, 0)
d1.pin_label("PWR_12V_PROT", 5, 0)
components.append(d1)

# D12 — TVS P6KE15A
d12 = Comp("Device:TVS", "D12", "P6KE15A", 62, 32,
           footprint="Diode_THT:D_DO-41_SOD81_P10.16mm_Horizontal")
d12.pin_label("PWR_12V_PROT", -5, 0)
d12.pin_label("GND",           5, 0)
components.append(d12)

# U2 — LM7805
u2 = Comp("Regulator_Linear:LM7805", "U2", "LM7805", 85, 25,
          footprint="Package_TO_SOT_THT:TO-220-3_Vertical")
u2.pin_label("PWR_12V_PROT", -7.62, 0)
u2.pin_label("GND",           0,    7.62)
u2.pin_label("PWR_5V",        7.62, 0)
components.append(u2)

# C1 — 100µF
c1 = Comp("Device:C", "C1", "100uF/25V", 105, 20,
          footprint="Capacitor_THT:C_Radial_D8.0mm_H11.5mm_P3.50mm")
c1.pin_label("PWR_5V", 0, -5)
c1.pin_label("GND",    0,  5)
components.append(c1)

# C2 — 100nF
c2 = Comp("Device:C", "C2", "100nF", 113, 20,
          footprint="Capacitor_THT:C_Disc_D3.8mm_W2.6mm_P2.50mm")
c2.pin_label("PWR_5V", 0, -5)
c2.pin_label("GND",    0,  5)
components.append(c2)

# ═══════════════════════════════════════════════════════════════════════
# БЛОК B — VOLTAGE DIVIDER  (x: 15-55, y: 65-105)
# ═══════════════════════════════════════════════════════════════════════

# R1 — 47kΩ (горе)
r1 = Comp("Device:R", "R1", "47k", 30, 72, rot=0,
          footprint="Resistor_THT:R_Axial_DIN0207_L6.3mm_D2.5mm_P10.16mm_Horizontal")
r1.pin_label("XENON_PWR",  0, -5)   # top → 12V (sense от F2 или акумулатор)
r1.pin_label("VBAT_ADC",   0,  5)   # bottom → to R2 junction
components.append(r1)

# R2 — 10kΩ (долу)
r2 = Comp("Device:R", "R2", "10k", 30, 87, rot=0,
          footprint="Resistor_THT:R_Axial_DIN0207_L6.3mm_D2.5mm_P10.16mm_Horizontal")
r2.pin_label("VBAT_ADC", 0, -5)   # top → to R1 junction
r2.pin_label("GND",       0,  5)  # bottom → GND
components.append(r2)

# ═══════════════════════════════════════════════════════════════════════
# БЛОК C — ОПТРОНИ  (x: 25-95, y: 110-185)
# ═══════════════════════════════════════════════════════════════════════

opto_data = [
    # (ref, y, net_anode_resistor, net_input, net_output, gpio_net)
    ("OK1", 118, "KL18_RAW",   "ACC_LED_K",   "ACC_GPIO",    "GPIO35"),
    ("OK2", 143, "AUTO_RAW",   "AUTO_LED_K",  "AUTO_GPIO",   "GPIO32"),
    ("OK3", 168, "UNLOCK_RAW", "UNLOCK_LED_K","UNLOCK_GPIO", "GPIO33"),
]

for i, (ref, y, net_in, led_k, out_net, gpio) in enumerate(opto_data):
    ri = i + 3  # R3, R5, R7
    rp = i * 2 + 4  # R4, R6, R8

    # Input resistor (4.7kΩ)
    rx = Comp("Device:R", f"R{ri*2-3}", "4k7", 35, y, rot=0,
              footprint="Resistor_THT:R_Axial_DIN0207_L6.3mm_D2.5mm_P10.16mm_Horizontal")
    rx.pin_label(net_in,  0, -5)
    rx.pin_label(led_k,   0,  5)
    components.append(rx)

    # PC817 optocoupler
    ok = Comp("Isolator:PC817", ref, "PC817", 58, y,
              footprint="Package_DIP:DIP-4_W7.62mm")
    ok.pin_label(led_k,  -7.62, -2.54)  # Anode
    ok.pin_label("GND",  -7.62,  2.54)  # Cathode
    ok.pin_label("PWR_3V3", 7.62, -2.54)  # Collector (via pullup)
    ok.pin_label(out_net, 7.62,  2.54)  # Emitter
    components.append(ok)

    # Pull-up resistor (10kΩ) — collector to 3.3V
    rpu = Comp("Device:R", f"R{rp}", "10k", 82, y - 5, rot=0,
               footprint="Resistor_THT:R_Axial_DIN0207_L6.3mm_D2.5mm_P10.16mm_Horizontal")
    rpu.pin_label("PWR_3V3", 0, -5)
    rpu.pin_label(out_net,   0,  5)
    components.append(rpu)

# Car input connector J2 (5-pin: KL18, AUTO, UNLOCK, GND, +12V)
j2 = Comp("Connector:Conn_01x05_Pin", "J2", "CAR_INPUTS", 18, 145,
          footprint="Connector_PinHeader_2.54mm:PinHeader_1x05_P2.54mm_Vertical")
j2.pin_label("KL18_RAW",   5, -5.08)
j2.pin_label("AUTO_RAW",   5, -2.54)
j2.pin_label("UNLOCK_RAW", 5,  0)
j2.pin_label("PWR_12V",    5,  2.54)
j2.pin_label("GND",        5,  5.08)
components.append(j2)

# ═══════════════════════════════════════════════════════════════════════
# БЛОК D — ESP32  (x: 110-215, y: 50-230)
# ═══════════════════════════════════════════════════════════════════════

esp = Comp("MCU_Module:ESP32_DevKitC_V4", "U1", "ESP32_DevKit_v1", 163, 140,
           footprint="Module:ESP32_DevKitC_v4")
# Outputs
esp.pin_label("GPIO26",   -30,  -55)   # Xenon MOSFET drive
esp.pin_label("GPIO27",   -30,  -50)   # Gabari relay
esp.pin_label("GPIO14",   -30,  -45)   # Fog relay
esp.pin_label("GPIO13",   -30,  -40)   # Illumination
# Inputs
esp.pin_label("GPIO34",    30,  -55)   # VBAT ADC
esp.pin_label("GPIO35",    30,  -50)   # ACC optocoupler
esp.pin_label("GPIO32",    30,  -45)   # AUTO optocoupler
esp.pin_label("GPIO33",    30,  -40)   # UNLOCK optocoupler (interrupt)
# Power
esp.pin_label("PWR_5V",   -30,   60)
esp.pin_label("GND",      -30,   65)
components.append(esp)

# 3.3V power label (ESP32 internal regulator output)
# PWR_3V3 is referenced by optocoupler pull-ups but sourced from ESP32 3V3 pin

# ═══════════════════════════════════════════════════════════════════════
# БЛОК E — КСЕНОН ИЗХОД  (x: 225-340, y: 20-70)
# ═══════════════════════════════════════════════════════════════════════

# R10 — 1kΩ, 2N7000 gate
r10 = Comp("Device:R", "R10", "1k", 230, 35, rot=0,
           footprint="Resistor_THT:R_Axial_DIN0207_L6.3mm_D2.5mm_P10.16mm_Horizontal")
r10.pin_label("GPIO26",     0, -5)
r10.pin_label("Q2_GATE",    0,  5)
components.append(r10)

# Q2 — 2N7000 (N-FET, IRF4905 gate driver)
q2 = Comp("Transistor_FET:2N7000", "Q2", "2N7000", 248, 35,
          footprint="Package_TO_SOT_THT:TO-92_Inline")
q2.pin_label("Q2_GATE",   -5,  2.54)   # Gate
q2.pin_label("XENON_GATE", 5, -2.54)   # Drain → IRF4905 gate
q2.pin_label("GND",        5,  2.54)   # Source
components.append(q2)

# R9 — 10kΩ, IRF4905 gate pull-up to 12V
r9 = Comp("Device:R", "R9", "10k", 265, 25, rot=0,
          footprint="Resistor_THT:R_Axial_DIN0207_L6.3mm_D2.5mm_P10.16mm_Horizontal")
r9.pin_label("XENON_PWR",  0, -5)
r9.pin_label("XENON_GATE", 0,  5)
components.append(r9)

# Q1 — IRF4905 (P-MOSFET, high-side xenon switch)
q1 = Comp("Transistor_FET:IRF4905", "Q1", "IRF4905", 283, 35,
          footprint="Package_TO_SOT_THT:TO-220-3_Vertical")
q1.pin_label("XENON_GATE", -5,  0)     # Gate
q1.pin_label("XENON_PWR",   0, -5.08)  # Source → fused 15A
q1.pin_label("XENON_SW",    5,  0)     # Drain → to D2
components.append(q1)

# D2 — 1N5408, our xenon decoupling diode (anode → XENON_SW, cathode → XENON_BALLAST)
d2 = Comp("Device:D", "D2", "1N5408", 305, 25,
          footprint="Diode_THT:D_DO-201AD_P15.24mm_Horizontal")
d2.pin_label("XENON_SW",       -5, 0)
d2.pin_label("XENON_BALLAST",   5, 0)
components.append(d2)

# D3 — 1N5408, BCM xenon decoupling diode (anode → BCM_XENON, cathode → XENON_BALLAST)
d3 = Comp("Device:D", "D3", "1N5408", 305, 38,
          footprint="Diode_THT:D_DO-201AD_P15.24mm_Horizontal")
d3.pin_label("BCM_XENON",     -5, 0)
d3.pin_label("XENON_BALLAST",  5, 0)
components.append(d3)

# J3 — ксенон конектори (3-pin: наш изход, BCM изход, кола)
j3 = Comp("Connector:Conn_01x03_Pin", "J3", "J_XENON", 330, 30,
          footprint="Connector_PinHeader_2.54mm:PinHeader_1x03_P2.54mm_Vertical")
j3.pin_label("XENON_BALLAST",  -5,  -2.54)
j3.pin_label("BCM_XENON",      -5,   0)
j3.pin_label("GND",            -5,   2.54)
components.append(j3)

# ═══════════════════════════════════════════════════════════════════════
# БЛОК F — ГАБАРИТИ РЕЛЕ  (x: 225-340, y: 80-120)
# ═══════════════════════════════════════════════════════════════════════

# R11 — 1kΩ, BC547 base (gabari)
r11 = Comp("Device:R", "R11", "1k", 230, 92, rot=0,
           footprint="Resistor_THT:R_Axial_DIN0207_L6.3mm_D2.5mm_P10.16mm_Horizontal")
r11.pin_label("GPIO27",      0, -5)
r11.pin_label("Q3_BASE",     0,  5)
components.append(r11)

# Q3 — BC547 (gabari relay driver)
q3 = Comp("Transistor_BJT:BC547", "Q3", "BC547", 248, 92,
          footprint="Package_TO_SOT_THT:TO-92_Inline")
q3.pin_label("Q3_BASE",           -5,  0)
q3.pin_label("RELAY_K1_COIL_N",    0, -5)
q3.pin_label("GND",                0,  5)
components.append(q3)

# K1 — реле габарити (SPDT 12V)
k1 = Comp("Relay:G5V-1", "K1", "Relay_12V", 270, 90,
          footprint="Relay_THT:Relay_SPDT_Omron_G5V-1")
k1.pin_label("RELAY_PWR",        -8, -5)  # Coil +
k1.pin_label("RELAY_K1_COIL_N",  -8,  5)  # Coil -
k1.pin_label("RELAY_PWR",         8, -5)  # NO → 12V за габарити
k1.pin_label("GABARI_SW",         8,  0)  # COM → our output
k1.pin_label("GND",               8,  5)  # NC → GND
components.append(k1)

# D8 — flyback диод K1
d8 = Comp("Device:D", "D8", "1N4007", 270, 107,
          footprint="Diode_THT:D_DO-41_SOD81_P10.16mm_Horizontal")
d8.pin_label("RELAY_K1_COIL_N", -5, 0)
d8.pin_label("RELAY_PWR",        5, 0)
components.append(d8)

# D4 — decoupling наш изход (anode → GABARI_SW, cathode → GABARI_WIRE)
d4 = Comp("Device:D", "D4", "1N4007", 305, 83,
          footprint="Diode_THT:D_DO-41_SOD81_P10.16mm_Horizontal")
d4.pin_label("GABARI_SW",   -5, 0)
d4.pin_label("GABARI_WIRE",  5, 0)
components.append(d4)

# D5 — decoupling BCM изход
d5 = Comp("Device:D", "D5", "1N4007", 305, 95,
          footprint="Diode_THT:D_DO-41_SOD81_P10.16mm_Horizontal")
d5.pin_label("BCM_GABARI",  -5, 0)
d5.pin_label("GABARI_WIRE",  5, 0)
components.append(d5)

# J4 — габарити конектор
j4 = Comp("Connector:Conn_01x03_Pin", "J4", "J_GABARI", 330, 90,
          footprint="Connector_PinHeader_2.54mm:PinHeader_1x03_P2.54mm_Vertical")
j4.pin_label("GABARI_WIRE", -5, -2.54)
j4.pin_label("BCM_GABARI",  -5,  0)
j4.pin_label("GND",         -5,  2.54)
components.append(j4)

# ═══════════════════════════════════════════════════════════════════════
# БЛОК G — МЪГЛА РЕЛЕ  (x: 225-340, y: 125-165)
# ═══════════════════════════════════════════════════════════════════════

r12 = Comp("Device:R", "R12", "1k", 230, 132, rot=0,
           footprint="Resistor_THT:R_Axial_DIN0207_L6.3mm_D2.5mm_P10.16mm_Horizontal")
r12.pin_label("GPIO14",   0, -5)
r12.pin_label("Q4_BASE",  0,  5)
components.append(r12)

q4 = Comp("Transistor_BJT:BC547", "Q4", "BC547", 248, 132,
          footprint="Package_TO_SOT_THT:TO-92_Inline")
q4.pin_label("Q4_BASE",           -5,  0)
q4.pin_label("RELAY_K2_COIL_N",    0, -5)
q4.pin_label("GND",                0,  5)
components.append(q4)

k2 = Comp("Relay:G5V-1", "K2", "Relay_12V", 270, 130,
          footprint="Relay_THT:Relay_SPDT_Omron_G5V-1")
k2.pin_label("RELAY_PWR",        -8, -5)
k2.pin_label("RELAY_K2_COIL_N",  -8,  5)
k2.pin_label("RELAY_PWR",         8, -5)
k2.pin_label("FOG_SW",            8,  0)
k2.pin_label("GND",               8,  5)
components.append(k2)

d9 = Comp("Device:D", "D9", "1N4007", 270, 147,
          footprint="Diode_THT:D_DO-41_SOD81_P10.16mm_Horizontal")
d9.pin_label("RELAY_K2_COIL_N", -5, 0)
d9.pin_label("RELAY_PWR",        5, 0)
components.append(d9)

d6 = Comp("Device:D", "D6", "1N4007", 305, 123,
          footprint="Diode_THT:D_DO-41_SOD81_P10.16mm_Horizontal")
d6.pin_label("FOG_SW",    -5, 0)
d6.pin_label("FOG_WIRE",   5, 0)
components.append(d6)

d7 = Comp("Device:D", "D7", "1N4007", 305, 135,
          footprint="Diode_THT:D_DO-41_SOD81_P10.16mm_Horizontal")
d7.pin_label("BCM_FOG",  -5, 0)
d7.pin_label("FOG_WIRE",  5, 0)
components.append(d7)

j5 = Comp("Connector:Conn_01x03_Pin", "J5", "J_FOG", 330, 130,
          footprint="Connector_PinHeader_2.54mm:PinHeader_1x03_P2.54mm_Vertical")
j5.pin_label("FOG_WIRE",  -5, -2.54)
j5.pin_label("BCM_FOG",   -5,  0)
j5.pin_label("GND",       -5,  2.54)
components.append(j5)

# ═══════════════════════════════════════════════════════════════════════
# БЛОК H — ILLUMINATION  (x: 225-340, y: 170-200)
# ═══════════════════════════════════════════════════════════════════════

r13 = Comp("Device:R", "R13", "1k", 230, 175, rot=0,
           footprint="Resistor_THT:R_Axial_DIN0207_L6.3mm_D2.5mm_P10.16mm_Horizontal")
r13.pin_label("GPIO13",   0, -5)
r13.pin_label("Q5_BASE",  0,  5)
components.append(r13)

q5 = Comp("Transistor_BJT:BC547", "Q5", "BC547", 248, 175,
          footprint="Package_TO_SOT_THT:TO-92_Inline")
q5.pin_label("Q5_BASE",   -5,  0)
q5.pin_label("ILLUM_SW",   0, -5)
q5.pin_label("GND",        0,  5)
components.append(q5)

# D10 — decoupling наш illumination изход
d10 = Comp("Device:D", "D10", "1N4007", 305, 168,
           footprint="Diode_THT:D_DO-41_SOD81_P10.16mm_Horizontal")
d10.pin_label("ILLUM_SW",    -5, 0)
d10.pin_label("ILLUM_WIRE",   5, 0)
components.append(d10)

# D11 — decoupling BCM illumination изход
d11 = Comp("Device:D", "D11", "1N4007", 305, 180,
           footprint="Diode_THT:D_DO-41_SOD81_P10.16mm_Horizontal")
d11.pin_label("BCM_ILLUM",  -5, 0)
d11.pin_label("ILLUM_WIRE",  5, 0)
components.append(d11)

j6 = Comp("Connector:Conn_01x03_Pin", "J6", "J_ILLUM", 330, 175,
          footprint="Connector_PinHeader_2.54mm:PinHeader_1x03_P2.54mm_Vertical")
j6.pin_label("ILLUM_WIRE", -5, -2.54)
j6.pin_label("BCM_ILLUM",  -5,  0)
j6.pin_label("GND",        -5,  2.54)
components.append(j6)

# ── Power symbols (GND и +12V навсякъде) ─────────────────────────────

pwr_syms = [
    ("GND",  18,  36),
    ("GND",  85,  35),
    ("GND", 105,  30),
    ("GND", 113,  30),
    ("GND",  30, 100),
    ("GND", 163, 210),
    ("GND", 248,  45),
    ("GND", 248, 102),
    ("GND", 248, 142),
    ("GND", 248, 185),
    ("+12V", 18,  20),
    ("+12V", 85,  17),
    ("+12V", 163, 55),
]

# ── Generate schematic ────────────────────────────────────────────────

def generate():
    lines = []
    lines.append("(kicad_sch")
    lines.append("  (version 20231120)")
    lines.append('  (generator "vectra_generate_kicad")')
    lines.append('  (generator_version "1.0")')
    lines.append('  (paper "A3")')
    lines.append("  (title_block")
    lines.append('    (title "Vectra C Auto Lights Controller")')
    lines.append('    (date "2026-05-07")')
    lines.append('    (rev "1.0")')
    lines.append('    (company "kkuninski-ops/vectra-c-auto-lights")')
    lines.append('    (comment 1 "MCU: ESP32 DevKit v1 — BLE via Nordic UART Service")')
    lines.append('    (comment 2 "Target: Opel Vectra C 2008 — D1S xenon")')
    lines.append("  )")
    lines.append("")
    lines.append("  (lib_symbols)")
    lines.append("")

    # Components
    for comp in components:
        lines.append(comp.render())
        lines.append("")

    # Power symbols
    for (name, x, y) in pwr_syms:
        lines.append(power_symbol(name, x, y))
        lines.append("")

    lines.append(")")
    return "\n".join(lines)

if __name__ == "__main__":
    content = generate()
    with open(OUT, "w", encoding="utf-8") as f:
        f.write(content)
    print(f"✓ Generated: {OUT}")
    print("  → Отвори в KiCad 10")
    print("  → Symbols → Update Symbols from Library")
    print("  → Свържи всеки пин с близкия net label")

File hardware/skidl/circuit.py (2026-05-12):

"""
Vectra C Auto Lights — SKiDL netlist
=====================================
Генерира KiCad-совместим нетлист от Python.

Изисква: pip install skidl
Употреба: python3 circuit.py
"""

from skidl import *

# ─── Библиотеки ─────────────────────────────────────────────────────────────
# Използваме KiCad стандартни библиотеки (Device, Connector_Generic и т.н.)

@package
def esp32_devkit():
    """ESP32 DevKit v1 — само използваните пинове"""

# ─── Нетове ─────────────────────────────────────────────────────────────────

# Захранване
KL30    = Net('+12V')       # Постоянно +12V от акумулатор
GND     = Net('GND')
VCC5    = Net('+5V')        # LM7805 изход
VCC33   = Net('+3V3')       # ESP32 3.3V изход (за pull-up)

# Входни сигнали (кола)
KL18_CAR   = Net('KL18_CAR')   # ACC от запалване
AUTO_CAR   = Net('AUTO_CAR')   # AUTO превключвател
UNLOCK_CAR = Net('UNLOCK_CAR') # Отключване (12V pulse)
VBAT_CAR   = Net('VBAT_CAR')   # Акумулаторно напрежение

# GPIO сигнали (ESP32)
GPIO34 = Net('GPIO34_ADC')
GPIO35 = Net('GPIO35_ACC')
GPIO32 = Net('GPIO32_AUTO')
GPIO33 = Net('GPIO33_UNLOCK')
GPIO26 = Net('GPIO26_XENON')
GPIO27 = Net('GPIO27_GABARI')
GPIO14 = Net('GPIO14_FOG')
GPIO13 = Net('GPIO13_ILLUM')

# Вътрешни нетове
GATE_IRF    = Net('GATE_IRF')       # IRF4905 Gate
XENON_OUT   = Net('XENON_OUT')      # Xenon балаcт вход (след диоди)
GABARI_OUT  = Net('GABARI_OUT')     # Габарити (след диоди)
FOG_OUT     = Net('FOG_OUT')        # Мъгла (след диоди)
ILLUM_OUT   = Net('ILLUM_OUT')      # Illumination (след диоди)

BCM_XENON  = Net('BCM_XENON')      # BCM ксенон изход
BCM_GABARI = Net('BCM_GABARI')     # BCM габарити изход
BCM_FOG    = Net('BCM_FOG')        # BCM мъгла изход
BCM_ILLUM  = Net('BCM_ILLUM')      # BCM illumination изход

RELAY_K1_NO = Net('K1_NO')         # Реле K1 — нормално отворен
RELAY_K2_NO = Net('K2_NO')         # Реле K2 — нормално отворен
RELAY_K1_C  = Net('K1_COIL_NEG')   # Реле K1 — бобина (-)
RELAY_K2_C  = Net('K2_COIL_NEG')   # Реле K2 — бобина (-)

# ─── Компоненти ─────────────────────────────────────────────────────────────

# --- Секция 1: Захранване ---

F1 = Part('Device', 'Fuse', footprint='Fuse:Fuseholder_Cylinder_5x20mm_Schurter_0031_8201_Horizontal_Open')
F1['A'] += KL30
F1['K'] += Net('F1_OUT')
F1.value = '1A'
F1.ref = 'F1'

D1 = Part('Device', 'D', footprint='Diode_THT:D_DO-41_SOD81_P10.16mm_Horizontal')
D1['A'] += Net('F1_OUT')
D1['K'] += Net('D1_OUT')
D1.value = '1N4007'
D1.ref = 'D1'

# TVS диод
D12 = Part('Device', 'D_Zener', footprint='Diode_THT:D_DO-201AD_P12.70mm_Horizontal')
D12['A'] += GND
D12['K'] += Net('D1_OUT')
D12.value = 'P6KE15A'
D12.ref = 'D12'

U2 = Part('Regulator_Linear', 'LM7805_TO220', footprint='Package_TO_SOT_THT:TO-220-3_Vertical')
U2['VI'] += Net('D1_OUT')
U2['GND'] += GND
U2['VO'] += VCC5
U2.ref = 'U2'

C1 = Part('Device', 'CP', footprint='Capacitor_THT:CP_Radial_D8.0mm_P3.50mm')
C1['+'] += VCC5
C1['-'] += GND
C1.value = '100uF/25V'
C1.ref = 'C1'

C2 = Part('Device', 'C', footprint='Capacitor_THT:C_Disc_D5.0mm_W2.5mm_P2.50mm')
C2[1] += VCC5
C2[2] += GND
C2.value = '100nF'
C2.ref = 'C2'

# --- Секция 2: Vbat делител ---

R1 = Part('Device', 'R', footprint='Resistor_THT:R_Axial_DIN0207_L6.3mm_D2.5mm_P10.16mm_Horizontal')
R1[1] += VBAT_CAR
R1[2] += GPIO34
R1.value = '47k'
R1.ref = 'R1'

R2 = Part('Device', 'R', footprint='Resistor_THT:R_Axial_DIN0207_L6.3mm_D2.5mm_P10.16mm_Horizontal')
R2[1] += GPIO34
R2[2] += GND
R2.value = '10k'
R2.ref = 'R2'

# --- Секция 3: Оптрони ---

# OK1 — KL18/ACC
R3 = Part('Device', 'R', footprint='Resistor_THT:R_Axial_DIN0207_L6.3mm_D2.5mm_P10.16mm_Horizontal')
R3[1] += KL18_CAR
R3[2] += Net('OK1_A')
R3.value = '4k7'
R3.ref = 'R3'

OK1 = Part('Isolator', 'PC817', footprint='Package_DIP:DIP-4_W7.62mm')
OK1['A']  += Net('OK1_A')
OK1['K']  += GND
OK1['C']  += GPIO35
OK1['E']  += GND
OK1.ref = 'OK1'

R4 = Part('Device', 'R', footprint='Resistor_THT:R_Axial_DIN0207_L6.3mm_D2.5mm_P10.16mm_Horizontal')
R4[1] += VCC33
R4[2] += GPIO35
R4.value = '10k'
R4.ref = 'R4'

# OK2 — AUTO
R5 = Part('Device', 'R', footprint='Resistor_THT:R_Axial_DIN0207_L6.3mm_D2.5mm_P10.16mm_Horizontal')
R5[1] += AUTO_CAR
R5[2] += Net('OK2_A')
R5.value = '4k7'
R5.ref = 'R5'

OK2 = Part('Isolator', 'PC817', footprint='Package_DIP:DIP-4_W7.62mm')
OK2['A']  += Net('OK2_A')
OK2['K']  += GND
OK2['C']  += GPIO32
OK2['E']  += GND
OK2.ref = 'OK2'

R6 = Part('Device', 'R', footprint='Resistor_THT:R_Axial_DIN0207_L6.3mm_D2.5mm_P10.16mm_Horizontal')
R6[1] += VCC33
R6[2] += GPIO32
R6.value = '10k'
R6.ref = 'R6'

# OK3 — UNLOCK
R7 = Part('Device', 'R', footprint='Resistor_THT:R_Axial_DIN0207_L6.3mm_D2.5mm_P10.16mm_Horizontal')
R7[1] += UNLOCK_CAR
R7[2] += Net('OK3_A')
R7.value = '4k7'
R7.ref = 'R7'

OK3 = Part('Isolator', 'PC817', footprint='Package_DIP:DIP-4_W7.62mm')
OK3['A']  += Net('OK3_A')
OK3['K']  += GND
OK3['C']  += GPIO33
OK3['E']  += GND
OK3.ref = 'OK3'

R8 = Part('Device', 'R', footprint='Resistor_THT:R_Axial_DIN0207_L6.3mm_D2.5mm_P10.16mm_Horizontal')
R8[1] += VCC33
R8[2] += GPIO33
R8.value = '10k'
R8.ref = 'R8'

# --- Секция 4: ESP32 ---

U1 = Part('RF_Module', 'ESP32-WROOM-32', footprint='RF_Module:ESP32-WROOM-32')
# Захранване
U1['GND'] += GND
U1['3V3'] += VCC33

# Входове
U1['IO34'] += GPIO34
U1['IO35'] += GPIO35
U1['IO32'] += GPIO32
U1['IO33'] += GPIO33

# Изходи
U1['IO26'] += GPIO26
U1['IO27'] += GPIO27
U1['IO14'] += GPIO14
U1['IO13'] += GPIO13
U1.ref = 'U1'

# --- Секция 5: Ксенон MOSFET ---

F2 = Part('Device', 'Fuse', footprint='Fuse:Fuseholder_Cylinder_5x20mm_Schurter_0031_8201_Horizontal_Open')
F2['A'] += KL30
F2['K'] += Net('F2_OUT')
F2.value = '15A'
F2.ref = 'F2'

R9 = Part('Device', 'R', footprint='Resistor_THT:R_Axial_DIN0207_L6.3mm_D2.5mm_P10.16mm_Horizontal')
R9[1] += Net('F2_OUT')   # pull-up to KL30 (через F2)
R9[2] += GATE_IRF
R9.value = '10k'
R9.ref = 'R9'

Q2 = Part('Device', 'Q_NMOS_GDS', footprint='Package_TO_SOT_THT:TO-92_Inline')
Q2['G'] += GPIO26
Q2['D'] += GATE_IRF
Q2['S'] += GND
Q2.value = '2N7000'
Q2.ref = 'Q2'

R10 = Part('Device', 'R', footprint='Resistor_THT:R_Axial_DIN0207_L6.3mm_D2.5mm_P10.16mm_Horizontal')
R10[1] += GPIO26
R10[2] += Net('Q2_G_RES')  # между GPIO26 и Q2 Gate
R10.value = '1k'
R10.ref = 'R10'

# Поправка: R10 е серийно между GPIO и Gate на Q2
Q2['G'] += Net('Q2_G_RES')

Q1 = Part('Device', 'Q_PMOS_GDS', footprint='Package_TO_SOT_THT:TO-220-3_Vertical')
Q1['G'] += GATE_IRF
Q1['D'] += Net('IRF_DRAIN')
Q1['S'] += Net('F2_OUT')  # Source към KL30 (след F2)
Q1.value = 'IRF4905'
Q1.ref = 'Q1'

D2 = Part('Device', 'D', footprint='Diode_THT:D_DO-201AD_P12.70mm_Horizontal')
D2['A'] += Net('IRF_DRAIN')
D2['K'] += XENON_OUT
D2.value = '1N5408'
D2.ref = 'D2'

D3 = Part('Device', 'D', footprint='Diode_THT:D_DO-201AD_P12.70mm_Horizontal')
D3['A'] += BCM_XENON
D3['K'] += XENON_OUT
D3.value = '1N5408'
D3.ref = 'D3'

# --- Секция 6: Реле K1 (Габарити) ---
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

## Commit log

2026-05-06 Initial commit — Vectra C Auto Lights Controller (ESP32 + BLE)
2026-05-06 Add illumination output — radio/cluster brightness follows AUTO state
2026-05-12 Add KiCad 10 schematic, PCB layout and SKiDL netlist
    - hardware/kicad/generate_kicad.py: Python generator → vectra-auto-lights.kicad_sch
    - hardware/kicad/vectra-auto-lights.kicad_sch: Full schematic (1888 lines, 8 sections)
    - hardware/kicad/vectra-auto-lights.kicad_pcb: 120×80mm 2-layer THT PCB layout
    - hardware/kicad/vectra-auto-lights.kicad_pro: KiCad project with design rules
    - hardware/kicad/README.md: KiCad usage instructions
    - hardware/skidl/circuit.py: SKiDL Python netlist definition
    [vectra-auto-lights.kicad_pcb, vectra-auto-lights.kicad_sch]
2026-05-13 Fix KiCad 10 compatibility: remove invalid syntax, fix library names
    PCB (.kicad_pcb):
    - Remove all ;; comments (not valid in S-expression format)
    - Replace incomplete footprint stubs with proper mounting hole pads
    - Keep board outline 120x80mm + GND pour; components added via
    Tools -> Update PCB from Schematic
    Schematic (.kicad_sch):
    - Opto:PC817 -> Isolator:PC817 (library renamed in KiCad 8+)
    - Relay:G5V-2 (DPDT) -> Relay:G5V-1 (SPDT, correct for K1/K2)
    - Regenerate vectra-auto-lights.kicad_sch
    [vectra-auto-lights.kicad_pcb, vectra-auto-lights.kicad_sch]
2026-05-13 Remove KiCad lock/history files, update .gitignore
2026-05-13 Add PCB component placer script (pcbnew Scripting Console)
    Run from KiCad PCB Editor → Tools → Scripting Console:
    exec(open('.../place_components.py').read())
    Places all 35 THT components at correct positions on 120x80mm board.
2026-05-13 docs: пълен pinout.md на български + обновени KiCad файлове
    - docs/pinout.md: преведен изцяло на чист български, добавена бърза
    справочна таблица с всички 9 сигнала (местоположение, пин, бушон,
    условие) — базирано на Ръководство 209, Глава 12 + схеми стр. 328-335
    - hardware/kicad/vectra-auto-lights.kicad_sch: обновена схема
    - hardware/kicad/vectra-auto-lights.kicad_pcb: обновен PCB layout
    - .gitignore: добавени KiCad autosave, backup и .kicad_prl файлове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
    [vectra-auto-lights.kicad_pcb, vectra-auto-lights.kicad_sch]
2026-05-14 feat(atopile): complete buildable PCB with all THT components
    - Installed 16 THT components via LCSC/EasyEDA (resistors, diodes,
    transistors, optocoupler, relay, capacitors, ESP32-WROOM-32E, etc.)
    - Manually created 5 packages using KiCad system footprints for parts
    unavailable via EasyEDA (IRF4905, 100nF cap, fuse holders, connectors)
    - Renamed component types in package files to our preferred names
    (Diode_1N4007, BC547, LM7805, etc.) to avoid atopile's IsSuperset
    inheritance constraint bug that breaks footprint parameter resolution
    - Added lowercase signal aliases directly in each package file
    (a/k for diodes, b/c/e for BJTs, g/d/s for MOSFETs, etc.)
    - Updated main.ato to import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
    [11.STEP, CAP-TH_BD8.0-P3.50-D0.5-FD.step, DIP-4_L4.6-W6.5-H3.5-LS7.62-P2.54.step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]
2026-05-15 feat(pcb): component placement + board outline 130×90mm
    - Placed all 48 components via pcbnew scripting (place_components.py)
    - Added Edge.Cuts rectangular outline 130×90 mm
    - Fixed atopile_address lookup (short form without VectraAutoLights. prefix)
    - Groups: connectors top, fuses, LM7805, optocouplers, ESP32,
    xenon MOSFET driver, gabari relay, fog relay, illum channel
    [default.kicad_pcb]
2026-05-22 feat(pcb): FreeRouting partial autoroute + improved component spacing
    - Increased component spacing (160x120mm board) to eliminate courtyard overlaps
    - Added place3.py with generous THT spacing (12-15mm between components)
    - FreeRouting autoroute: 35 connections not found (down from 47)
    - Exported DSN/SES for FreeRouting workflow
    - Remaining: fix D2/D3 short, route 35 ESP32 GPIO connections
    [default.dsn, default.kicad_pcb]
